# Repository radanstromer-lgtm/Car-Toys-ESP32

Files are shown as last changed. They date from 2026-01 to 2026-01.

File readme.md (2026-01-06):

# 🏎️ ESP32 RC Car Upgrade (JR-RX Replacement)







Watch the Demo Video (https://youtu.be/zVmI0E0HFQA)

> **From Web to Wheels:** A project converting a standard kid's ride-on car (previously using a broken JR-RX receiver) into a smart, Bluetooth-controlled vehicle using an ESP32 and high-power motor drivers.

---

## 📖 Table of Contents

- [Background](#-background)
- [Features](#-features)
- [Hardware Required](#-hardware-required)
- [Wiring Diagram & Pinout](#-wiring-diagram--pinout)
- [Software & Installation](#-software--installation)
- [Control & App](#-control--app)
- [Troubleshooting](#-troubleshooting)
- [Author](#-author)

---

## 🧐 Background

This project was born out of a need to repair a kid's ride-on car with a faulty stock receiver (JR-RX type). Instead of buying a proprietary replacement, I decided to upgrade the system entirely using an **ESP32**.

As a **Frontend Developer**, diving into hardware provided a unique perspective on how code interacts with the physical world. This project replaces the old system control of the original car with smooth **PWM-based acceleration (Soft Start)** and robust Bluetooth connectivity.

---

## ✨ Features

- **Bluetooth Classic Control:** Uses `BluetoothSerial` for reliable connection with Android phones.
- **High Power Driver:** Utilizes **BTS7960** (43A) drivers to handle heavy loads and steep inclines.
- **Soft Start Algorithm:** Prevents "whiplash" by gradually increasing PWM value, ensuring smooth acceleration for the child's safety.
- **Separate Steering Control:** Dedicated driver/channel for the steering motor.
- **Resource Optimized:** Hardwired "Enable" pins to 5V to save GPIO pins on the ESP32.

---

## 🛠 Hardware Required

| Component | Quantity | Description |
| --- | --- | --- |
| **ESP32 DevKit V1** | 1 | The main microcontroller. |
| **BTS7960 Motor Driver** | 2 | High current H-Bridge (One for Drive, One for Steer). |
| **LM2596 Step Down** | 1 | Buck converter (12V Battery -> 5V for ESP32). |
| **Jumper Wires** | - | Female-to-Female & Male-to-Female. |
| **12V Battery** | 1 | Existing car battery. |
| **Android Phone** | 1 | For the controller app. |

---

## 🔌 Wiring Diagram & Pinout

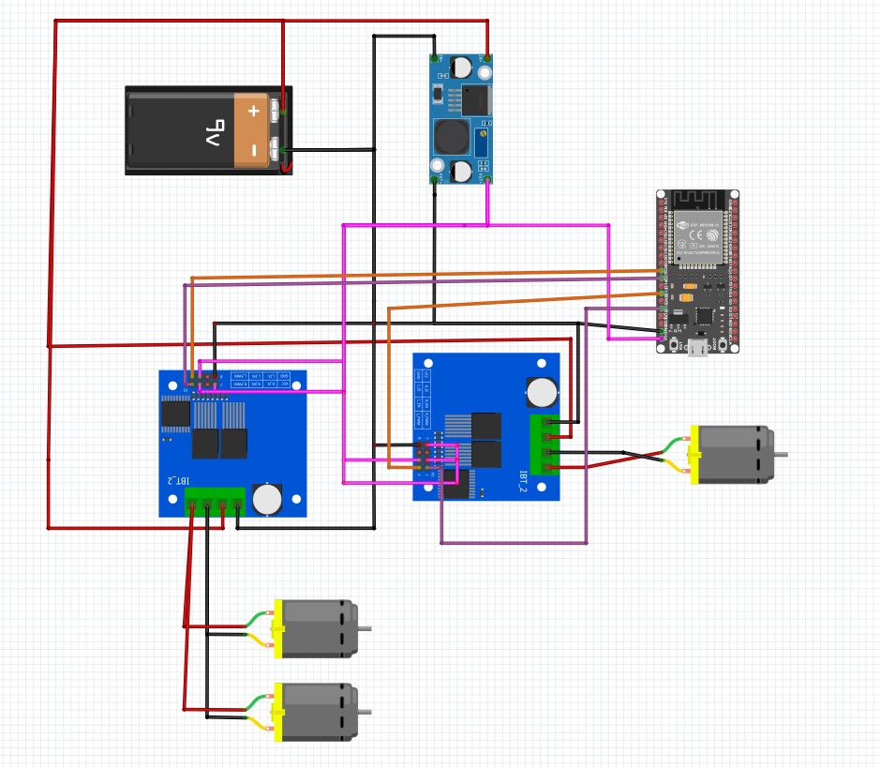
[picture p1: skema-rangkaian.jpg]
Wiring Diagram Schematic


> _Figure: Complete wiring schematic connecting ESP32, BTS7960 Drivers, and Step Down Converter._

### 1. Main Power Circuit (12V Battery)

Connect the main power source from the Battery to the step-down converter and motor drivers.

- **Battery + (Positive)** connects to 3 points:
  - LM2596S pin `IN+`
  - BTS7960 #1 (Drive) pin `B+`
  - BTS7960 #2 (Steering) pin `B+`
- **Battery - (Negative/GND)** connects to 3 points:
  - LM2596S pin `IN-`
  - BTS7960 #1 (Drive) pin `B-`
  - BTS7960 #2 (Steering) pin `B-`

### 2. Logic Power Circuit (5V System)

This system uses 5V voltage provided by the LM2596S to power the ESP32 and logic pins.

> **⚠️ CRITICAL: Ensure the LM2596S output is adjusted to 5V using a multimeter BEFORE connecting to the ESP32!**

- **LM2596S pin OUT+ (5V)** connects to:
  - ESP32 pin `VIN`
  - BTS7960 #1 pin `VCC`
  - BTS7960 #1 pin `R_EN` & `L_EN` (To keep the driver always enabled)
  - BTS7960 #2 pin `VCC`
  - BTS7960 #2 pin `R_EN` & `L_EN` (To keep the driver always enabled)
- **LM2596S pin OUT- (GND)** connects to:
  - ESP32 pin `GND`

### 3. Output Circuit (To Motors)

Connecting the drivers to the physical DC motors.

- BTS7960 #1 pin `M+` & `M-` $\to$ Main Drive Motor (Type 380/390/550)
- BTS7960 #2 pin `M+` & `M-` $\to$ Front Steering Motor

### ⚠️ Important Notes

1. **Common Ground:** Ensure the Battery GND, ESP32 GND, and Driver GND are all connected together.
2. **Enable Pins:** `R_EN` and `L_EN` on the BTS7960 are connected directly to **5V** (VCC) to save ESP32 pins.

### 4. Pin Configuration Table

| ESP32 Pin | Component Pin | Function |
| --- | --- | --- |
| **VIN** | LM2596 OUT+ | 5V Power Input |
| **GND** | LM2596 OUT- | Ground |
| **GPIO 26** | Rear Driver RPWM | Drive Forward |
| **GPIO 27** | Rear Driver LPWM | Drive Reverse |
| **GPIO 12** | Steer Driver RPWM  | Turn Right |
| **GPIO 13** | Steer Driver LPWM  | Turn Left |
| **-** | Driver R_EN / L_EN | **Connect to 5V** |

---

## 💻 Software & Installation

### Prerequisites

1. **Arduino IDE** installed.

### Installation Steps

1. Clone this repository:

```bash
git clone https://github.com/radanstromer-lgtm/Car-Toys-ESP32

```

2. Open the `.ino` file in Arduino IDE.
3. Select Board: **DOIT ESP32 DEVKIT V1**.
4. **Crucial Setting:** Go to `Tools` > `Partition Scheme` and select **"Huge APP (3MB No OTA/1MB SPIFFS)"**.

- _Note: This is required because the `BluetoothSerial.h` library is large._

5. Connect ESP32 via USB.
6. Click **Upload**.

- _Tip: If it gets stuck at `Connecting...`, hold the **BOOT** button on the ESP32 until writing begins._

---

## 📱 Control & App

You can use any "Bluetooth Serial Terminal" app from the Play Store.

- **Device Name:** `Mobil_ESP32_Final`
- **Baud Rate:** 9600 (Standard Bluetooth)

### Control Mapping (Characters)

| Character | Action |
| --- | --- |
| **W** | Move Forward (Press)  |
| **w** | Stop Moving (Release) |
| **S** | Move Backward (Press) |
| **s** | Stop Moving (Release) |
| **A** | Turn Left (Press) |
| **D** | Turn Right (Press) |

---

## ⌨️ Bonus: Control via PC Keyboard (Python)

I have included a Python script (`remote.py`) that allows you to drive the car using your laptop's keyboard (WASD keys). This is perfect for testing or if you prefer physical keys over a touchscreen.

### Prerequisites

- **Python 3.x** installed on your computer.
- **Bluetooth** capability on your PC/Laptop.

### Setup Instructions

1.  **Pair the Device:**

    - Go to your PC's Bluetooth settings.
    - Pair with **`Mobil_ESP32_Final`**.
    - _Note: If asked for a PIN, try `0000` or `1234`._

2.  **Find the COM Port:**

    - Once paired, Windows will assign COM ports to the device.
    - Open **Device Manager** > **Ports (COM & LPT)**.
    - Look for "Standard Serial over Bluetooth link". You might see two ports; usually, you need the **Outgoing** port (or try both if unsure).

3.  **Install Dependencies:**
    Open your terminal/command prompt and install the required libraries:

    ```bash
    pip install pyserial keyboard
    ```

4.  **Configure the Script:**
    - Open `remote.py` in your code editor.
    - Update the `bluetooth_port` variable with your specific COM port (e.g., `'COM5'`).
    - Save the file.

### How to Run

Run the script as Administrator (required for the `keyboard` library to intercept key presses globally):

```bash
python remote.py
```

## 🔧 Troubleshooting

**Issue: "Guru Meditation Error" or Boot Loop**

- **Fix:** Ensure you are using a stable power supply (LM2596). If using Arduino IDE 2.0+, try downgrading the ESP32 Board Manager to version `2.0.17` if `3.0.x` causes PWM issues.

**Issue: Bluetooth not showing up**

- **Fix:** Check if `Partition Scheme` is set to "Huge APP". Standard partition is often too small for the Bluetooth stack.

**Issue: Car wheels spin immediately upon boot**

- **Fix:** Ensure the wiring is correct and grounds are connected. Always test with wheels off the ground first!

---

## 👨‍💻 Author

**Dadan**

- _Frontend Developer & DIY Enthusiast_
- Connect on LinkedIn 
- Follow on Instagram 

---

_Disclaimer: This project involves modifying electrical components. Proceed at your own risk. Always disconnect the battery when working on wiring._

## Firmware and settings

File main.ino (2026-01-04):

#include "BluetoothSerial.h"

#if !defined(CONFIG_BT_ENABLED) || !defined(CONFIG_BLUEDROID_ENABLED)
#error Bluetooth is not enabled!
#endif

BluetoothSerial SerialBT;

// --- PIN PWM BTS7960 ---
// Motor Penggerak (Modul #1)
#define PIN_DRIVE_FWD 26 
#define PIN_DRIVE_REV 27

// Motor Setir (Modul #2)
#define PIN_STEER_RIGHT 12
#define PIN_STEER_LEFT  13

// --- PIN ENABLE BTS7960 ---
// Motor Penggerak
#define PIN_DRIVE_REN 32
#define PIN_DRIVE_LEN 33

// Motor Setir
#define PIN_STEER_REN 14
#define PIN_STEER_LEN 15

// PWM CONFIG
const int pwmFreq = 5000;
const int pwmRes = 8;

// Variabel motor
int maxDriveSpeed = 200;
int targetDriveSpeed = 0;
int currentDriveSpeed = 0;
int driveDirection = 0;

int maxSteerSpeed = 255;
int targetSteerSpeed = 0;
int currentSteerSpeed = 0;
int steerDirection = 0;

const int ACCEL_STEP = 10;
// const int ACCEL_INTERVAL = 20;
const int ACCEL_INTERVAL = 500;
unsigned long lastAccelTime = 0;

void setup() {
  Serial.begin(115200);
  SerialBT.begin("Mobil_ESP32_BTS7960");
  Serial.println("Driver BTS7960 Siap. Kirim WSAD.");

  // --- Set pin EN sebagai OUTPUT ---
  pinMode(PIN_DRIVE_REN, OUTPUT);
  pinMode(PIN_DRIVE_LEN, OUTPUT);
  pinMode(PIN_STEER_REN, OUTPUT);
  pinMode(PIN_STEER_LEN, OUTPUT);

  // Matikan semua EN saat boot (AMAN)w
  digitalWrite(PIN_DRIVE_REN, LOW);
  digitalWrite(PIN_DRIVE_LEN, LOW);
  digitalWrite(PIN_STEER_REN, LOW);
  digitalWrite(PIN_STEER_LEN, LOW);

  // --- Set PWM ---
  ledcAttach(PIN_DRIVE_FWD,  pwmFreq, pwmRes);
  ledcAttach(PIN_DRIVE_REV,  pwmFreq, pwmRes);
  ledcAttach(PIN_STEER_RIGHT, pwmFreq, pwmRes);
  ledcAttach(PIN_STEER_LEFT,  pwmFreq, pwmRes);

  // Matikan PWM
  ledcWrite(PIN_DRIVE_FWD, 0);
  ledcWrite(PIN_DRIVE_REV, 0);
  ledcWrite(PIN_STEER_RIGHT, 0);
  ledcWrite(PIN_STEER_LEFT, 0);
}

// =========================================================
// MOTOR PENGGERAK
// =========================================================
void handleDriveAcceleration() {
  if (currentDriveSpeed < targetDriveSpeed) {
    currentDriveSpeed += ACCEL_STEP;
    if (currentDriveSpeed > targetDriveSpeed) currentDriveSpeed = targetDriveSpeed;
  } else if (currentDriveSpeed > targetDriveSpeed) {
    currentDriveSpeed -= ACCEL_STEP;
    if (currentDriveSpeed < targetDriveSpeed) currentDriveSpeed = targetDriveSpeed;
  }

  if (currentDriveSpeed == 0) {
    // Stop
    ledcWrite(PIN_DRIVE_FWD, 0);
    ledcWrite(PIN_DRIVE_REV, 0);
    digitalWrite(PIN_DRIVE_REN, LOW);
    digitalWrite(PIN_DRIVE_LEN, LOW);
    driveDirection = 0;
    return;
  }

  // Enable dulu
  digitalWrite(PIN_DRIVE_REN, HIGH);
  digitalWrite(PIN_DRIVE_LEN, HIGH);

  if (driveDirection == 1)  {  // MAJU
    ledcWrite(PIN_DRIVE_FWD, currentDriveSpeed);
    ledcWrite(PIN_DRIVE_REV, 0);
  } else if (driveDirection == -1) {  // MUNDUR
    ledcWrite(PIN_DRIVE_FWD, 0);
    ledcWrite(PIN_DRIVE_REV, currentDriveSpeed);
  }
}

// =========================================================
// MOTOR SETIR
// =========================================================
void handleSteerAcceleration() {
  if (currentSteerSpeed < targetSteerSpeed) {
    currentSteerSpeed += ACCEL_STEP;
    if (currentSteerSpeed > targetSteerSpeed) currentSteerSpeed = targetSteerSpeed;
  } else if (currentSteerSpeed > targetSteerSpeed) {
    currentSteerSpeed -= ACCEL_STEP;
    if (currentSteerSpeed < targetSteerSpeed) currentSteerSpeed = targetSteerSpeed;
  }

  if (currentSteerSpeed == 0) {
    ledcWrite(PIN_STEER_RIGHT, 0);
    ledcWrite(PIN_STEER_LEFT, 0);
    digitalWrite(PIN_STEER_REN, LOW);
    digitalWrite(PIN_STEER_LEN, LOW);
    steerDirection = 0;
    return;
  }

  // Aktifkan EN
  digitalWrite(PIN_STEER_REN, HIGH);
  digitalWrite(PIN_STEER_LEN, HIGH);

  if (steerDirection == 1) { // KANAN
    ledcWrite(PIN_STEER_RIGHT, currentSteerSpeed);
    ledcWrite(PIN_STEER_LEFT, 0);
  } else if (steerDirection == -1) { // KIRI
    ledcWrite(PIN_STEER_RIGHT, 0);
    ledcWrite(PIN_STEER_LEFT, currentSteerSpeed);
  }
}

// =========================================================
// LOOP
// =========================================================
void loop() {
  if (SerialBT.available()) {
    char cmd = SerialBT.read();
    Serial.println(cmd);

    switch (cmd) {
      case 'W':
        driveDirection = 1;
        targetDriveSpeed = maxDriveSpeed;
        break;
      case 'S':
        driveDirection = -1;
        targetDriveSpeed = maxDriveSpeed;
        break;
      case 'w':
      case 's':
        targetDriveSpeed = 0;
        break;

      case 'D':
        steerDirection = 1;
        targetSteerSpeed = maxSteerSpeed;
        break;
      case 'A':
        steerDirection = -1;
        targetSteerSpeed = maxSteerSpeed;
        break;
      case 'd':
      case 'a':
        targetSteerSpeed = 0;
        break;
    }
  }

  if (millis() - lastAccelTime > ACCEL_INTERVAL) {
    lastAccelTime = millis();
    handleDriveAcceleration();
    handleSteerAcceleration();
  }
}

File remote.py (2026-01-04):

import serial
import keyboard
import time

# --- PENGATURAN ---
# GANTI 'COMx' DENGAN COM PORT OUTGOING ANDA (Contoh: 'COM5')
bluetooth_port = 'COM3' 
baud_rate = 115200

try:
    ser = serial.Serial(bluetooth_port, baud_rate, timeout=1)
    print(f"Terhubung ke {bluetooth_port}. Gunakan WSAD untuk mengemudi!")
    print("Tekan ESC untuk keluar.")
except Exception as e:
    print(f"Gagal terhubung: {e}")
    print("Pastikan Bluetooth terhubung dan COM Port benar.")
    exit()

# Status tombol untuk mencegah pengiriman data berulang-ulang
keys_status = {'w': False, 's': False, 'a': False, 'd': False}

def send_command(char):
    try:
        ser.write(char.encode())
        # print(f"Sent: {char}") # Uncomment untuk debugging
    except:
        print("Error mengirim data")

while True:
    try:
        # --- MAJU (W) ---
        if keyboard.is_pressed('w'):
            if not keys_status['w']: # Jika sebelumnya belum ditekan
                send_command('W')
                keys_status['w'] = True
        else:
            if keys_status['w']: # Jika sebelumnya ditekan, sekarang dilepas
                send_command('w')
                keys_status['w'] = False

        # --- MUNDUR (S) ---
        if keyboard.is_pressed('s'):
            if not keys_status['s']:
                send_command('S')
                keys_status['s'] = True
        else:
            if keys_status['s']:
                send_command('s')
                keys_status['s'] = False

        # --- KIRI (A) ---
        if keyboard.is_pressed('a'):
            if not keys_status['a']:
                send_command('A')
                keys_status['a'] = True
        else:
            if keys_status['a']:
                send_command('a')
                keys_status['a'] = False

        # --- KANAN (D) ---
        if keyboard.is_pressed('d'):
            if not keys_status['d']:
                send_command('D')
                keys_status['d'] = True
        else:
            if keys_status['d']:
                send_command('d')
                keys_status['d'] = False

        # Keluar Program
        if keyboard.is_pressed('esc'):
            print("Keluar...")
            break
            
        time.sleep(0.01) # Delay kecil agar CPU tidak panas

    except KeyboardInterrupt:
        break

ser.close()

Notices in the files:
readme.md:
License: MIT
